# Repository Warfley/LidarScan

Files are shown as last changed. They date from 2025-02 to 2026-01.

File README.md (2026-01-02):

# LIDAR based 3D Room Scanner

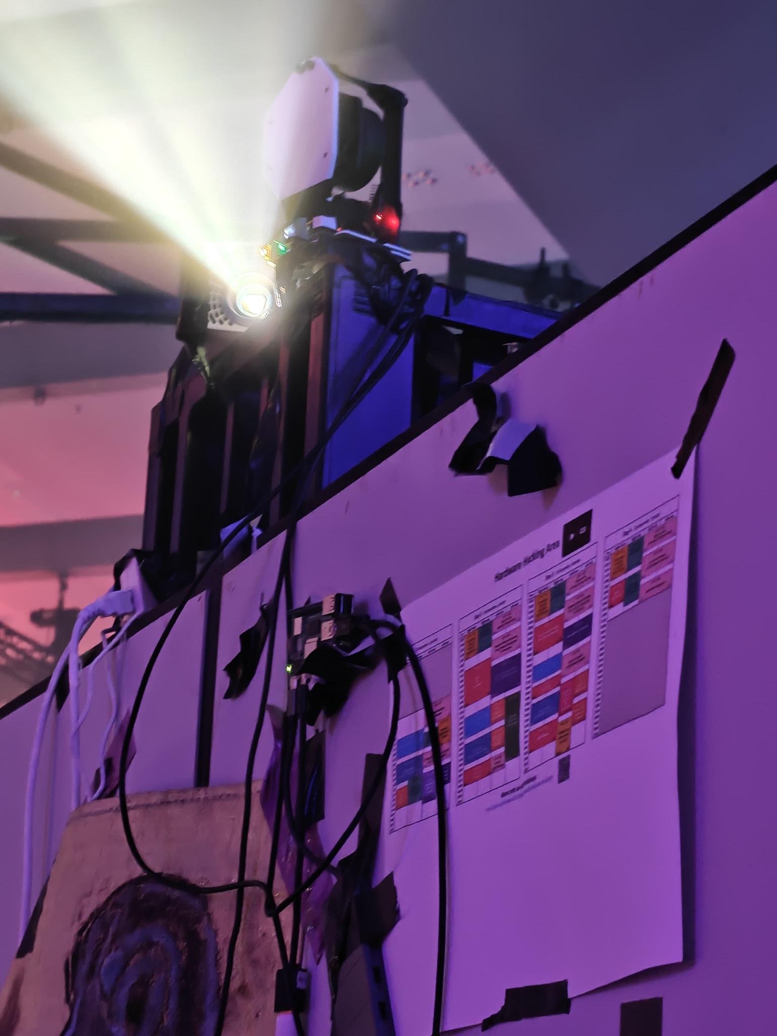
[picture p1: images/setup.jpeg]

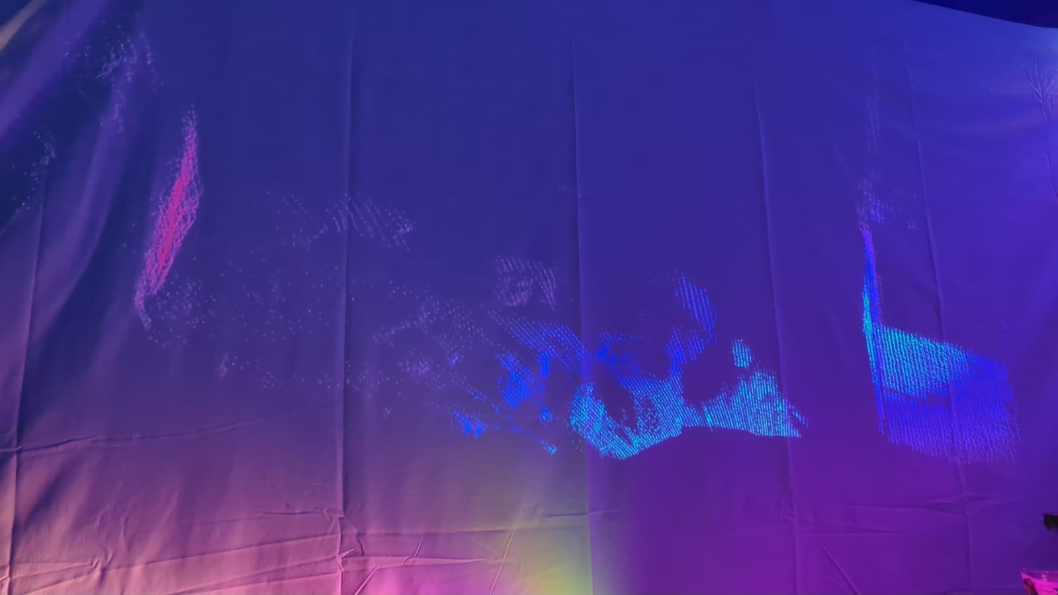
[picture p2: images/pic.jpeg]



## Prequesites
Besides the specific components used to build this project, the following Hardware and Software is required:

1. 3D Printer: I used the Anycubic Kobra 3
2. Soldering Iron
3. Basic Tooling (screw drivers, ruler, level, etc)
4. Linux (I didn't bother trying to build this for windows) with the following software:
    * [OpenSCAD](https://openscad.org/)
    * [ESP-IDF](https://docs.espressif.com/projects/esp-idf/en/stable/esp32/get-started/linux-macos-setup.html)
    * C++ Tooling (Clang, Make, etc.)
5. Consumables (Filament, lubrication oil)

### Components
The following components where used for the project. Added (non affiliate) links to Amazon, and prices, but the same components can be bough cheaper on other platforms as well:
1. [SlamTec RPLidar A1](https://www.amazon.de/dp/B07VLFGT27) (70€)
2. [ESP32 Development Board](https://www.amazon.de/dp/B0DGG7LXMF) (8€)
3. [M996R Servo](https://www.amazon.de/dp/B07H87592P) (32€): Technically only one is required, but quality varies a lot, so you may need to test out a few to find one that works well enough
4. [8 times M2x6, 4 times M2.5x8, 12 times M3x8 screws](https://www.amazon.de/dp/B0DBTNWDJB) (5€)
5. [2 times M5x16 6x M5x12 screws](https://www.amazon.de/dp/B0D258MS9F) (15€)
6. 8 times M3 nuts (included above)
7. [4 times M2x4 and 4 M2x3, 6 times M5x6, 2 times M5x10 and 1 quarter inch thread insert](https://www.amazon.de/dp/B0D1VKC5K9) (15€)
8. [Ball bearing turning table](https://www.amazon.de/dp/B0B3X7R961) (8€)
9. [Camera Tripod](https://www.amazon.de/dp/B0B8YHTWGY) (33€)

The total cost for me therefore was around 185€ as an initial cost. But with most of the screws and threads being more than you need for one project, and ESP32 and M996 being quite expensive on Amazon, the whole project can probably be done with a budget of around 120€.

## Building
To build the Project first the hardware needs to be printed and assembled.

### 3D Printing

The [platform.scad](CAD/platform.scad) contains the CAD files for all the 3D printable parts, but as a single file and arranged in position of assembly.
The file contains 6 different objects:
1. Tripod Mount
2. Bottom platform
3. Top Platform
4. Lidar Mount
5. 2 Beams for fixating the Lidar mount further

To print these parts, you need to isolate each part (by setting all other part visibilities to false in the beginning of the scad file), rendering that part and exporting it to STL.

All parts are designed that, when oriented correctly, they can be printed without supports.

My colorized print takes around 6 hours for a full print of all parts, on two different plates, and consumes roughly 110g of PLA filament.

### Assembling the Print

After printing, the thread inserts need to be melted into the 3D prints using a soldering iron.

#### Tripod Mount
On the bottom you need to melt in the quarter inch thread insert, and on the top 4 M3x4 threads on which the bottom platform will be screwd onto.

#### Bottom Platform
The bottom platform has in the middle the mount point for the servo. Here you need to insert 4 M2x4 threads.

Afterwards you can screw the platform onto the tripod mount using 4 M3x6 screws.
Once the Tripod Mount is attached to the bottom platform, screw it onto the turning table using 4 M3x6 screws and fixate using nuts.

Add 4 M3x6 screws to the top of the turning table, and fixate with nuts. The nuts will serve as padding between the turning table and the top platform, which wil be put on to p of the M3 screws.

#### Lidar Mount
Add the 2 M5x10 thread inserts at the bottom. Afterwards screw the M2.5x8 screws in the holes on the back. Note the holes are designed that the head of the screw can be inserted deep into the print.

Fixate the RPLidar A1 using the M2.5 screws.

#### Beams
Add the 6 M5x6 inserts into the ends of the beams. Screw the smaller beam to the top of the larger one using M5x12 screws.
The feet point inwards on both beams.

#### Top Patform
The top platform has 4 inlets for mounting the servo onto. Add 4 M2x3 thread inserts in the yellow tubes.

Afterwards screw the Lidard mount very tightly using 2 M5x16 screws onto the top platform, as well as the long beam using 2 M5x12 screws and the end of the short beam to the top of the Lidar mount using the last 2 M5x2 screws.

Note the top beam adds an obstacle for the scan. As it is on top where usually only the roof of the room is, this is usually not an issue. But if you want a clear scan of the top of the lidar, you can also remove the beam but this may result in some shakier measurements when the lidar is running.

After assembling the platform and lidar mount, put it on top of the turning table, using the already prepared screws and fixate using nuts.

Do not yet add the servo, as it needs to be set to the 0 position first.

#### Tripod
Once you assembled all the parts as described above, you can simply mount it on the tripod using the quarter inch screw insert on the bottom.

## Software
The software for this project consists of three programs:
1. The control software for the servo running on the esp
2. The software performing the scan and collecting the pointcloud
3. A visualization software for viewing, filtering and exporting the pointcloud

### Servo Control
The first program located in the `servocontrol` directory uses an ESP to read control commands via serial and uses them to adjust the servo to certain degrees. The software was written for an ESP32 as this was the development board available for the project. But as servo is controlled via a single PWM pin and none of the more advanced features of the ESP are used, smaller and cheaper boards like the ESP c3 mini or something even smaller like an AVR could also be used.
Also a consideration may be to combine the servo controlling functionality with the scanning on a raspberry pi or similar devices that support hardware PWM.

The code is written using the plain ESP-IDF without any advanced libraries like arduino, which provides high speed 16 bit resolution PWM channels. Porting to smaller ESP boards may therefore require to adjust some of these settings. Most importantly, with changing the bitsize of the PWM channel the absolute values for relative percentages change.

To use this software simply build with the ESP-IDF and flash to your ESP board:
```bash
$ idf.py build
$ idf.py -p /dev/ttyUSB0 flash
```

#### Calibration
Once you power the ESP and connect the servo (pin 18 in this configuration) the servo should be turning rougly to the origin. The exact orientation at which PWM value is highly dependent on the product and therefore requires calibration. Additionally the servo insert only fits the insert at certain angles, meaning after the servo has been resetted to the origin position, it can be assmbled and calibrated.

For the final part of the assembly mount the servo onto the bottom platoform such when mounting on the top platform the black arrow of the top platform is roughly at or slightly below the the rightmost edge of the scale of the bottom platform. It does not need to align perfectly. Screw the servo on and connect it back to the ESP.

To start the calibration connect the ESP to the computer and open up a COM terminal to the ESP command line interface:
```bash
$ idf.py -p /dev/ttyUSB0 monitor
# Or if no esp-idf available
$ screen /dev/ttyUSB0 115200
[...]
|>
```
In this interface you can start the calibration with
```bash
|> calibrate start 1000 3000
```
This will start the calibration process for the 0° PWM value with between 1000 and 3000. The calibration consists of a binary search where at each step you need to check the needed if it's above or below the 0° point on the measurement scale of the bottom platform and then react with `+` or `-` to go higher or lower respectively.

After you did the 0° calibration, do the same for the 180° calibration:
```bash
|> calibrate stop 7000 9000
```
Note if you are using a different ESP with a different resolution, e.g. the c3 mini with only 14 bit resolution, you must adjust these values accordingly (value/2^16*2^14). Also before running adjust `DEFAULT_START` and `DEFAULT_STOP` in the C code accordingly, otherwise the servo might be fried.

After calibration you can test a few different angles using the set command:
```bash
|> set 0
|> set 10
|> set 45
|> set 90
|> set 112.5
|> set 180
```
And see if it moves as expected.

The calibrated values are not stored permanently in the ESP, if you want to make these calibrations permanent, simply change the defines `DEFAULT_START` and `DEFAULT_STOP` with the new values and compile and re-flash.

Once calbibration is finished you are good to go and start scanning.

### Scanning Application
The scanning application is a Linux only application written in C++ located in `scanapp`. It relies on the RP-Lidar SDK to communicate with the lidar. The RP-Lidar SDK is included as a submodule in this repository, so make sure you checked out all the submodules before running the make script.

The build script requires clang as c++ compiler, even though the code should be fully ISO C++ 20 compliant and therefore also be compilable with g++ if the buildscript is adjusted. To build just run `make` and the executable should be compiled into `bin/scanapp`.

To start scanning you need to provide the COM ports to the lidar and the ESP as command line arguments. Additionally further arguments can be specified to either narrow the scan range or specify output formats. For further details see the help page. To give an example:
```bash
bin/scanapp -b scan.dat -l 315 -l 45 -f 60 -t 120 -s 0.5 /dev/ttyUSB0 /dev/ttyUSB1
```
This scans a narrow area in front of the scanner 60°-120° horizontally and vertically the slice between 315° and 40° (going over 0/360, as 0° is directly in front of the scanner and 90° and 270° being straight up and down). It has a step width of half a degree. This should give quite a high resolution scan of something, e.g. a person in front of the scanner.

It should be noted that the effectively reachable resolution depends on the servo. Not all can reach 0.5° horizontal resolution. In those cases it will become a sort of "ghost" resolution, where the application believes the servo has moved but the points received are the same as before just copying the same points at an offset. The best way to figure out whats the smalles resolution the servo can achieve is to set different angles and feel or hear if the servo starts moving:
```bash
# idf.py -p /dev/ttyUSB0 monitor
|> set 10
|> set 11
|> set 11.5
|> set 30
|> set 30.5
|> set 30.75
...
```
Note it's to be expected that with small resolutions the servo may from time to time skip a step, as long as most of the time it's still moving it should be fine.

That said, the ghost resolution can also be useful from time to time as a form of interpolation.

#### Live Rendering

The software also allow live rendering and updating while scanning. This can be done with the `--preview`/`-p` flag. Additionally the `--continuous`/`-c` can be used to instead of doing a single scan to continuously update the resulting image with new data.
The visualization is still not that fleshed out, e.g. all the parameters for the viewing angles, movement, zoomm, etc. are currently hardcoded in the code.

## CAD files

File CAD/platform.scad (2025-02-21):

show_tripod_mount=true;
show_bottom_platform=true;
show_top_platform=true;
show_lidar_mount=true;
show_beam1=true;
show_beam2=true;

// Extra width for mount: 1mm
mount_width = 1;
mount_offset = 1;
$fn=60;

module screw_mount_cylinder(h, d, fw=mount_width) {
    cylinder(h=h+fw, r=d/2 + mount_width);
}

module screw_mount(h, d, fw=mount_width) {
    difference() {
        screw_mount_cylinder(h,d,fw);
        translate([0,0,fw])
            cylinder(h=h, r=d/2);
    }
}

// quarter inch screw mount
module tripod_mount(w,screw_distance,screw_height,screw_socket_size=/*M3*/5) {
    union() {
        rotate([180,0,0])
        translate([screw_distance/2,screw_distance/2,-screw_height-mount_width])
            screw_mount(screw_height,screw_socket_size);
        rotate([180,0,0])
        translate([-screw_distance/2,screw_distance/2,-screw_height-mount_width])
            screw_mount(screw_height,screw_socket_size);
        rotate([180,0,0])
        translate([screw_distance/2,-screw_distance/2,-screw_height-mount_width])
            screw_mount(screw_height,screw_socket_size);
        rotate([180,0,0])
        translate([-screw_distance/2,-screw_distance/2,-screw_height-mount_width])
            screw_mount(screw_height,screw_socket_size);
        translate([0,0,1.3])
            screw_mount(12.7, 8);
        difference() {
            cylinder(h=15,r1=w,r2=w*0.50);
            translate([0,0,1.3])
                screw_mount_cylinder(12.7, 8-mount_width);
            translate([screw_distance/2,screw_distance/2,0])
                screw_mount_cylinder(screw_height,screw_socket_size-mount_width*2);
            translate([-screw_distance/2,screw_distance/2,0])
                screw_mount_cylinder(screw_height,screw_socket_size-mount_width*2);
            translate([screw_distance/2,-screw_distance/2,0])
                screw_mount_cylinder(screw_height,screw_socket_size-mount_width*2);
            translate([-screw_distance/2,-screw_distance/2,0])
                screw_mount_cylinder(screw_height,screw_socket_size-mount_width*2);
        }
    }
}

module mount_plattform(w,screw_offset,screw_distance,screw_size=/*M3*/3.5) {
    union() {
        if (screw_offset>0) {
            translate([(screw_distance/2),(screw_distance/2),0])
                screw_mount(screw_offset,screw_size,0);
            translate([-(screw_distance/2),(screw_distance/2),0])
                screw_mount(screw_offset,screw_size,0);
            translate([(screw_distance/2),-(screw_distance/2),0])
                screw_mount(screw_offset,screw_size,0);
            translate([-(screw_distance/2),-(screw_distance/2),0])
                screw_mount(screw_offset,screw_size,0);
        }
        difference() {
            translate([0,0,-1.5])
                minkowski() {
                    cube([w-8,w-8,1], true);
                    cylinder(1,r=4);
                }
            translate([(screw_distance/2),(screw_distance/2),-3])
                screw_mount_cylinder(screw_offset+3,screw_size-mount_width*2);
            translate([-(screw_distance/2),(screw_distance/2),-3])
                screw_mount_cylinder(screw_offset+3,screw_size-mount_width*2);
            translate([(screw_distance/2),-(screw_distance/2),-3])
                screw_mount_cylinder(screw_offset+3,screw_size-mount_width*2);
            translate([-(screw_distance/2),-(screw_distance/2),-3])
                screw_mount_cylinder(screw_offset+3,screw_size-mount_width*2);
        }
    }
}


module servo_mount(w,h,screw_distance,screw_height,screw_socket_size=/*M2*/3.2) {
    screw_offset=h-1;
    top_widht=screw_distance/2+screw_socket_size/2+mount_width*2;
    union() {
        translate([(screw_distance/2),0,screw_offset])
            screw_mount(screw_height, screw_socket_size);
        translate([-(screw_distance/2),0,screw_offset])
            screw_mount(screw_height, screw_socket_size);
        translate([0,(screw_distance/2),screw_offset])
            screw_mount(screw_height, screw_socket_size);
        translate([0,-(screw_distance/2),screw_offset])
            screw_mount(screw_height, screw_socket_size);
        difference() {
            cylinder(h, r1=w/2,r2=top_widht);
            translate([(screw_distance/2),0,screw_offset])
                screw_mount_cylinder(screw_height, screw_socket_size-mount_width);
            translate([-(screw_distance/2),0,screw_offset])
                screw_mount_cylinder(screw_height, screw_socket_size-mount_width);
            translate([0,(screw_distance/2),screw_offset])
                screw_mount_cylinder(screw_height, screw_socket_size-mount_width);
            translate([0,-(screw_distance/2),screw_offset])
                screw_mount_cylinder(screw_height, screw_socket_size-mount_width);
        }
    }
}

module servo_frame(w,l,h,hw1,hw2,screw_position,screw_distance,screw_offset=2,screw_height=4,screw_socket_size=/*M2*/3.2) {
    union() {
        translate([l/2+screw_position,(screw_distance/2),h-screw_height-mount_width+screw_offset])
            screw_mount(screw_height, screw_socket_size);
        translate([l/2+screw_position,-(screw_distance/2),h-screw_height-mount_width+screw_offset])
            screw_mount(screw_height, screw_socket_size);
        translate([-l/2-screw_position,(screw_distance/2),h-screw_height-mount_width+screw_offset])
            screw_mount(screw_height, screw_socket_size);
        translate([-l/2-screw_position,-(screw_distance/2),h-screw_height-mount_width+screw_offset])
            screw_mount(screw_height, screw_socket_size);
        difference() {
            translate([0,0,(h-1-screw_offset)/2-1])
                // unline the other plattform, be at least as thick as screws to ensure it prints a good floor
                minkowski() {
                    cube([l*1.25,w,h-1-screw_offset+2],center=true);
                    cylinder(1,r=4);
                }
            translate([-10,0,0])
                cylinder(h=h-screw_offset,r1=hw1,r2=hw2);
            translate([-10,0,-2])
                cylinder(h=2,r=hw1);
            translate([0,0,h/2-screw_offset])
                cube([l,w+8,h],center=true);
            translate([l/2+screw_position,(screw_distance/2),h-screw_height-mount_width+screw_offset])
                screw_mount_cylinder(screw_height, screw_socket_size-mount_width);
            translate([l/2+screw_position,-(screw_distance/2),h-screw_height-mount_width+screw_offset])
                screw_mount_cylinder(screw_height, screw_socket_size-mount_width);
            translate([-l/2-screw_position,(screw_distance/2),h-screw_height-mount_width+screw_offset])
                screw_mount_cylinder(screw_height, screw_socket_size-mount_width);
            translate([-l/2-screw_position,-(screw_distance/2),h-screw_height-mount_width+screw_offset])
                screw_mount_cylinder(screw_height, screw_socket_size-mount_width);
        }
    }
}

module measurement_ring(w,h,screw_distance,screw_socket_size=/*M3*/3.7) {
    difference() {
        union() {
            color("white")
            cylinder(h=h,r=w/2);
            color("black")
            for (tick=[0:1:180]) {
                rotate(tick,[0,0,1])
                    translate([0,(w/2)-2,2.2])
                    if (tick % 10 == 0) {
                        translate([0,-1,0])
                            cube([0.4,6,0.4], center=true);
                    } else {
                        cube([0.4,4,0.4], center=true);
                    }
            }
        }
        translate([w/4,0,1])
            cube([w/2,w,h*2],center=true);

        // copied from mount_platform above
        translate([-(screw_distance/2),(screw_distance/2),-1])
            screw_mount_cylinder(6,4);
        translate([-(screw_distance/2),-(screw_distance/2),-1])
            screw_mount_cylinder(6,4);
    }
}
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

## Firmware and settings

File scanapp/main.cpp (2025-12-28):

#include <iostream>
#include <string>
#include <thread>
#include <chrono>
#include <fstream>
#include <optional>
#include <cmath>

#include "servo.h"
#include "lidar.h"
#include "renderer.h"
#include "pointscan.h"


using namespace sl;

bool parse_float(char const *s, double *out) {
    int part=0;
    int base=1;
    bool infrac=false;
    *out=0;
    if (!*s) return false;
    for (;*s;++s) {
        switch(*s) {
        case '0':
        case '1':
        case '2':
        case '3':
        case '4':
        case '5':
        case '6':
        case '7':
        case '8':
        case '9':
            part = part * 10 + *s-'0';
            base *= 10;
            break;
        case '.':
            if (infrac) return false;
            infrac = true;
            *out=part;
            base=1;
            part=0;
            break;
        default: return false;
        }
    }
    *out = infrac
         ? *out + (double)part / base
         : part;
    return true;
}

struct args : public ScanArgs{
    std::optional<std::string> json_out;
    std::optional<std::string> binary_out;
    std::optional<std::string> asc_out;
    bool preview=false;
};

static inline std::optional<std::string> parse_argname(char const *arg) {
    if (arg[0]!='-') {
        return {};
    }
    std::string result = arg + 1 + (arg[1]=='-');
    return result == "b" ? "binary"
         : result == "j" ? "json"
         : result == "a" ? "asc"
         : result == "d" ? "distance"
         : result == "l" ? "low"
         : result == "h" ? "high"
         : result == "f" ? "from"
         : result == "t" ? "to"
         : result == "s" ? "step"
         : result == "r" ? "rotations"
         : result == "v" ? "verbose"
         : result == "c" ? "continuous"
         : result == "p" ? "preview"
         : result;
}

std::optional<args> parse_args(int argc, char const **argv) {
    args result;
    std::string arg_name="";
    for (int i=1;i<argc;++i) {
        auto try_name = parse_argname(argv[i]);
        if (try_name) {
            if (!arg_name.empty()) {
                std::cerr << "Invalid parameter for argument --" << arg_name << std::endl;
                return {};
            }
            if (*try_name=="verbose") {
                result.verbose=true;
                continue;
            }
            if (*try_name=="continuous") {
                result.continuous=true;
                continue;
            }
            if (*try_name=="preview") {
                result.preview=true;
                continue;
            }
            arg_name = *try_name;
            continue;
        }
        if ((arg_name=="from" && !parse_float(argv[i],&result.start)) ||
            (arg_name=="to" && !parse_float(argv[i],&result.stop)) ||
            (arg_name=="step" && !parse_float(argv[i],&result.step)) ||
            (arg_name=="rotations" && !parse_float(argv[i],&result.rotations)) ||
            (arg_name=="distance" && !parse_float(argv[i],&result.max_distance)) ||
            (arg_name=="low" && !parse_float(argv[i],&result.low_angle)) ||
            (arg_name=="high" && !parse_float(argv[i],&result.high_angle))
        ) {
            std::cerr << "Invalid floating point value " << argv[i] << std::endl;
            return {};
        } else if (arg_name=="binary") {
            result.binary_out = std::string(argv[i]);
        } else if (arg_name=="json") {
            result.json_out = std::string(argv[i]);
        } else if (arg_name=="asc") {
            result.asc_out = std::string(argv[i]);
        } else if (arg_name=="" && result.lidar_port.empty()) {
            result.lidar_port = std::string(argv[i]);
        } else if (arg_name=="" && result.servo_port.empty()) {
            result.servo_port = std::string(argv[i]);
        } else if (arg_name=="") {
            std::cerr << "Unknown positional argument " << argv[i] << std::endl;
            return {};
        }
        arg_name="";
    }
    if (!arg_name.empty()) {
        std::cerr << "Invalid parameter for argument --" << arg_name << std::endl;
        return {};
    }
    if (result.lidar_port.empty() || result.servo_port.empty()) {
        return {};
    }
    if (result.start<0 || result.stop>180 || result.stop < result.start || result.step<0) {
        std::cerr << "Invalid scan range " << result.start << ".." << result.stop << ":" << result.step << std::endl;
        return {};
    }
    if (result.rotations<=0) {
        std::cerr << "Invalid number of rotations per scan " << result.rotations << std::endl;
        return {};
    }
    return result;
}

void print_help(char const *exec) {
    std::cerr << "Usage: " << exec << " [OPTIONS] LIDAR_PART SERVO_PORT\n"
              << "\n"
              << "Options:\n"
              << "  -b --binary      | Output file for binary scan data\n"
              << "  -j --json        | Output file for JSON scan data\n"
              << "  -a --asc         | Output file for ASC scan data\n"
              << "  -d --distance    | Maximum distance for points (default: 32)\n"
              << "  -h --high        | Maximum angle for points (default: 360)\n"
              << "  -l --low         | Minimum angle for points (default: 0)\n"
              << "  -f --from        | Start of scan range in degrees (default 0)\n"
              << "  -t --to          | Stop of scan range in degrees (default 180)\n"
              << "  -s --step        | Step size of scan range in degrees (default 1)\n"
              << "  -r --rotations   | Number of rotational scans per step (default 1)\n"
              << "  -v --verbose     | Print servo terminal output to STDOUT\n"
              << "  -c --continuous  | do a continuous analysis\n"
              << "  -p --preview     | Show a preview of the point cloud during scan\n"
              << "\n"
              << "Binary data format:\n"
              << "  Header:\n"
              << "  *----------------*---------------*---------------*\n"
              << "  | 'LIDARSCAN\\0' (char[10]) | Version 1 (uint32) |\n"
              << "  *------------------------------------------------*\n"
              << "  | Start (Double) | Stop (Double) | Step (Double) |\n"
              << "  *------------------------------------------------*\n"
              << "  | Rotations (Double) |  Points Per Scan (sint32) |\n"
              << "  *--------------------*---------------------------*\n"
              << "  |                    Points...                   |\n"
              << "  *------------------------------------------------*\n"
              << "  Point Format:\n"
              << "  *---------------*----------------*-------------------*-----------------*\n"
              << "  |  Yaw (Double) | Pitch (Double) | Distance (Double) | Quality (uint8) |\n"
              << "  *---------------*----------------*-------------------*-----------------*\n"
              << "\n"
              << "asc Format: X Y Z <Intensity>\n";
}

int main(int argc, char const **argv) {
    auto args = parse_args(argc, argv);
    if (!args) {
        print_help(argv[0]);
        return 1;
    }

    PointScan scan(*args);
    if (!scan.connect()) {
        return 1;
    }
    scan.start();

    std::ofstream json_out;
    std::ofstream binary_out;
    std::ofstream asc_out;

    if (args->json_out) {
        json_out.open(args->json_out.value());
    }
    if (args->binary_out) {
        binary_out.open(args->binary_out.value(), std::ios::binary);
    }
    if (args->asc_out) {
        asc_out.open(args->asc_out.value());
    }

    if (json_out.is_open()) {
        json_out << "{\n"
                << "  \"start\": " << args->start << ",\n"
                << "  \"stop\": "  << args->stop  << ",\n"
                << "  \"step\": "  << args->step  << ",\n";
    }
    if (binary_out.is_open()) {
        constexpr std::size_t MAGIC_LEN=10;
        char const MAGIC[MAGIC_LEN] = "LIDARSCAN";
        std::uint32_t const version = 1;
        binary_out.write(MAGIC, MAGIC_LEN);
        binary_out.write(reinterpret_cast<char const *>(&version), sizeof(version));

        binary_out.write(reinterpret_cast<char const *>(&args->start), sizeof(args->start));
        binary_out.write(reinterpret_cast<char const *>(&args->stop), sizeof(args->stop));
        binary_out.write(reinterpret_cast<char const *>(&args->step), sizeof(args->step));
    }
    if (json_out.is_open()) {
        json_out << "  \"pps\": " << scan.points_per_scan() << ",\n"
                 << "  \"rotations\": " << args->rotations << ",\n"
                 << "  \"points\": [\n";
    }
    if (binary_out.is_open()) {
        auto pps=scan.points_per_scan();
        binary_out.write(reinterpret_cast<char const *>(&args->rotations), sizeof(args->rotations));
        binary_out.write(reinterpret_cast<char const *>(&pps), sizeof(pps));
    }

    if (args->preview) {
        start_renderer(&scan, argc, const_cast<char**>(argv));
    }
    scan.wait_for();

    scan.process_data<void>([&](auto &slices) {
        auto first_printed = false;
        for (auto const &slice : slices) {
            for (auto const &p : slice.points) {
                if (scan.filter_point(p)) {
                    continue;
                }
                if (json_out.is_open()) {
                    if (first_printed) {
                        json_out << ",\n";
                    }
                    json_out << "    {\n"
                            << "      \"pitch\": "    << p.pitch << ",\n"
                            << "      \"yaw\": "      << slice.degree << ",\n"
                            << "      \"distance\": " << p.distance << ",\n"
                            << "      \"quality\": "  << static_cast<int>(p.quality) << "\n"
                            << "    }";
                    first_printed=true;
                }
                if (binary_out.is_open()) {
                    binary_out.write(reinterpret_cast<char const *>(&slice.degree), sizeof(slice.degree));
                    binary_out.write(reinterpret_cast<char const *>(&p.pitch), sizeof(p.pitch));
                    binary_out.write(reinterpret_cast<char const *>(&p.distance), sizeof(p.distance));
                    binary_out.write(reinterpret_cast<char const *>(&p.quality), sizeof(p.quality));
                }
                if (asc_out.is_open()) {
                    auto pt=convert_point(p,slice.degree);
                    asc_out << pt.x << " " << pt.y << " " << pt.z << " " << (std::int32_t)p.quality << " 255 255 255 " << -pt.x/p.distance << " " << -pt.y/p.distance << " " << -pt.z/p.distance << "\n";
                }
            }
            if (json_out.is_open() && slice.degree+args->step<=args->stop) {
                json_out << ",\n";
            }
        }
    });
    if (json_out.is_open()) {
        json_out << "\n"
                 << "  ]\n"
                 << "}";
    }

    return 0;
}

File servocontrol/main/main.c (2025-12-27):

#include <stdio.h>
#include <stdint.h>
#include <stdbool.h>
#include <string.h>

#include "freertos/FreeRTOS.h"
#include "freertos/task.h"
#include "driver/ledc.h"

#include "esp_system.h"
#include "esp_log.h"
#include "esp_err.h"

#define MIN_VAL 500
#define MAX_VAL 9000

#define DEFAULT_START 1500
#define DEFAULT_STOP 7600

static char const *TAG = "Servo Control";

ledc_timer_config_t setup_timer(uint32_t freq, bool highspeed) {
    static int timer_id = 0;
    ESP_ERROR_CHECK(timer_id>=LEDC_TIMER_MAX);
    ESP_LOGI(TAG, "Setup Timer %d for PWM with resolution 1024", timer_id);
    ledc_timer_config_t conf = {
        .speed_mode = highspeed ? LEDC_HIGH_SPEED_MODE : LEDC_LOW_SPEED_MODE,
        .duty_resolution = LEDC_TIMER_16_BIT,
        .timer_num = timer_id++,
        .freq_hz = freq,
        .clk_cfg = LEDC_AUTO_CLK
    };
    ESP_ERROR_CHECK(ledc_timer_config(&conf));
    return conf;
}

ledc_channel_config_t setup_channel(ledc_timer_config_t const *timer, int pinno) {
    static int hs_channel_id = 0;
    static int ls_channel_id = 0;
    int * const channel_id = timer->speed_mode==LEDC_HIGH_SPEED_MODE
                         ? &hs_channel_id
                         : &ls_channel_id;
    ESP_ERROR_CHECK(*channel_id >= LEDC_CHANNEL_MAX);
    ESP_LOGI(TAG, "Setup PIN %d for PWM", pinno);
    ledc_channel_config_t config = {
        .gpio_num = pinno,
        .speed_mode = timer->speed_mode,
        .channel = (*channel_id)++,
        .intr_type = LEDC_INTR_DISABLE,
        .timer_sel = timer->timer_num,
        .duty = 0,
        .hpoint = 0,
    };
    ledc_channel_config(&config);
    return config;
}

static inline void update_pwm(ledc_channel_config_t const *channel, uint32_t value) {
    ESP_ERROR_CHECK(ledc_set_duty(channel->speed_mode,channel->channel,value));
    ESP_ERROR_CHECK(ledc_update_duty(channel->speed_mode,channel->channel));
}

static inline void set_degree(ledc_channel_config_t const *channel,
                              uint16_t start, uint16_t stop,
                              double degree) {
    int value = (int)(degree/180 * (stop-start) + start);
    update_pwm(channel, value);
    ESP_LOGI(TAG, "Updateing to %f (%d)", degree, value);
}

static char next_char(bool peek) {
    static char buff = '\0';
    static bool hasbuff = false;
    if (!hasbuff) {
        for (;fread(&buff, sizeof(buff), 1, stdin)!=1;vTaskDelay(100/portTICK_PERIOD_MS));
        printf("%c", buff);
        fflush(stdout);
    }
    // If peeking keep buffer
    hasbuff = peek;
    return buff;
}

static inline void discard_rest_of_line(void) {
    for (char c=0;c!='\n';c=next_char(false));
}

int read_line(char *buff, int buff_len) {
    int result = 0;
    for (;result<buff_len-1;++result) {
        char c = next_char(false);
        if (c=='\n') {
            buff[result]='\0';
            return result;
        } else {
            buff[result]=c;
        }
    }
    // Last element must be \0
    buff[buff_len-1] = '\0';
    if (next_char(true)=='\n') {
        // fits exactly buffer
        next_char(false);
        return buff_len-1;
    }
    discard_rest_of_line();
    return -1;
}

static inline void skip_spaces(void) {
    for(char c=next_char(true);c==' ';c=next_char(true)) {
        next_char(false);
    }
}

int read_token(char *buff, int buff_len) {
    int result = 0;
    skip_spaces();
    for (;result<buff_len-1;++result) {
        char c = next_char(true);
        if ((c>='A' && c<='Z') ||
            (c>='a' && c <= 'z')) {
            buff[result]=c;
            // consume
            next_char(false);
        } else {
            buff[result]='\0';
            return result;
        }
    }
    // buffer to small
    buff[buff_len-1] = '\0';
    return -1;
}

bool read_float(double *d) {
    bool infrac = false;
    bool result = false;
    int part = 0;
    int base = 1;
    skip_spaces();
    while (true) {
        char c = next_char(true);
        if (c>='0' && c<='9') {
            part = part * 10 + (int)(c-'0');
            base *= 10;
        } else if (c=='.' && !infrac) {
            *d = part;
            part = 0;
            base = 1;
            infrac=true;
        } else {
            if (infrac) {
                *d += (double)part / base;
            } else {
                *d = part;
            }
            break;
        }
        // Consume char if no early return
        next_char(false);
        result = true;
    }
    return result;
}

bool read_int(int *i) {
    bool result = false;
    *i = 0;
    skip_spaces();
    while (true) {
        char c = next_char(true);
        if (c>='0' && c<='9') {
            *i = *i * 10 + (int)(c-'0');
        } else {
            break;
        }
        // Consume char if no early return
        next_char(false);
        result = true;
    }
    return result;
}

static inline bool consume_eol(const char *cmd) {
    if (next_char(false)!='\n') {
        printf("Unknown parameter for command %s\n", cmd);
        discard_rest_of_line();
        return false;
    }
    return true;
}

int32_t binary_search(ledc_channel_config_t const *channel,
                   uint16_t start, uint16_t stop) {
    char buff[2];
    if (start < MIN_VAL || stop >= MAX_VAL) {
        ESP_LOGE(TAG, "Invalid binary search range [%d..%d]", start, stop);
        return -1;
    }
    printf("Starting binary search [%d..%d]\n", start, stop);
    while (start < stop) {
        uint16_t current = (stop-start) / 2 + start;
        printf("Setting motor to %d", current);
        update_pwm(channel, current);
        printf("More (+), Less (-), accept (a) or Cancel (c)\n");
        if (read_line(buff, sizeof(buff)) != 1) {
            printf("Unknown command\n");
            continue;
        }
        switch (buff[0]) {
            case '+':
                start = current;
                break;
            case '-':
                stop = current;
                break;
            case 'a':
                start = current;
                break;
            case 'c':
                printf("Canceled binary search\n");
                return -1;
            default:
                printf("Unknown command %s\n", buff);
        }
    }
    printf("Binary search finished, result: %d\n", start);
    return start;
}
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

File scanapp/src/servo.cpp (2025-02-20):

#include "servo.h"

#include <sstream>

extern "C" {
    #include <asm/termbits.h>
    #include <sys/ioctl.h>
    #include <unistd.h>
    #include <fcntl.h>
}

void Servo::handle_output() {
        char buff[1024];
        int num_bytes;
        std::size_t bytes_read;

        if (!*this) {
            return;
        }
        if (ioctl(fd, FIONREAD, &num_bytes) < 0 || num_bytes <= 0) {
            return;
        }

        do {
            bytes_read = read(fd, buff, sizeof(buff));
            if (output) {
                output->write(buff,bytes_read);
            }

        } while (bytes_read == sizeof(buff));
}

void Servo::disconnect() {
    if (fd < 0) {
        return;
    }
    close(fd);
    fd = -1;
}


bool Servo::connect() {
    struct termios tty;
    struct termios2 tty2;
    fd = open(port.c_str()  ,O_RDWR | O_NOCTTY);

    if (fd < 0) {
        return false;
    }

    // Setting termio flags
    tty.c_cflag =  CS8 | CLOCAL | CREAD;
    tty.c_oflag = 0;
    tty.c_lflag = 0;       //ICANON;
    tty.c_cc[VMIN]=0;
    tty.c_cc[VTIME]=1;     // time out every .1 sec
    if (ioctl(fd,TCSETS,&tty) < 0) {
        disconnect();
        return false;
    }

    // Using termios2 for baud rate
    if (ioctl(fd,TCGETS2,&tty2) < 0) {
        disconnect();
        return false;
    }
    tty2.c_cflag &= ~CBAUD;
    tty2.c_cflag |= BOTHER;
    tty2.c_ispeed = baud;
    tty2.c_ospeed = baud;
    if (ioctl(fd,TCSETS2,&tty2) < 0) {
        disconnect();
        return false;
    }

    // Flush anything thats currently in the buffer
    if (ioctl(fd,TCFLSH,TCIOFLUSH) < 0) {
        disconnect();
        return false;
    }

    return true;
}

bool Servo::set_degree(double degree) {
    if (!*this) {
        return false;
    }
    std::stringstream ss;
    ss << "set " << degree << "\n";

    std::size_t res = write(fd, ss.str().data(), ss.str().length());
    handle_output();
    return res == ss.str().length();
}

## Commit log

2025-02-13 Fixing screws and changing to LF ending
    [platform.scad]
2025-02-15 Fixing sizes in CAD
    [platform.scad]
2025-02-15 CAD: Adjusted height of servo mount point
    [platform.scad]
2025-02-15 Servocontrol: Fixing command line bugs
    [main.c]
2025-02-15 CAD: fixing melt
    [platform.scad]
2025-02-15 Measuring range for test servo
2025-02-16 CAD: Adding top platform with servo frame
    [platform.scad]
2025-02-17 Adding degree gauge
    [platform.scad]
2025-02-18 CAD: Completing design and splitting up prints
    [gears.scad, platform.scad]
2025-02-19 CAD: Fixing lidar skrew offset
    [platform.scad]
2025-02-19 CAD: Measurement updates
    [platform.scad]
2025-02-19 CAD: Centering LIDAR
    [platform.scad]
2025-02-20 Servo: Calibration
2025-02-20 Servo: Adding terminal script
2025-02-20 CAD: Increasing thickness of lidar mount to avoid wobbling
    [platform.scad]
2025-02-20 Scanapp: Code to move servo and scan with lidar
2025-02-21 CAD: Adding support frame to reduce wobbling
    [platform.scad]
2025-03-15 Printing points in json
2025-12-27 Moving scan to a seperate thread for glut rendering"
